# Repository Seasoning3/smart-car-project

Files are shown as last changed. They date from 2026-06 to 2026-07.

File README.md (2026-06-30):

# Smart Vehicle

## 1. Project Overview
This project implements a small embedded vehicle platform that integrates power distribution, PWM-based motor and steering control, camera-based ArUco marker detection, and a web-based control interface.

The main objective was to design and test a hardware-software integrated system.  
The project focused on power stability, actuator control, web-to-vehicle communication.

## 2. Project Images
### Vehicle Prototype
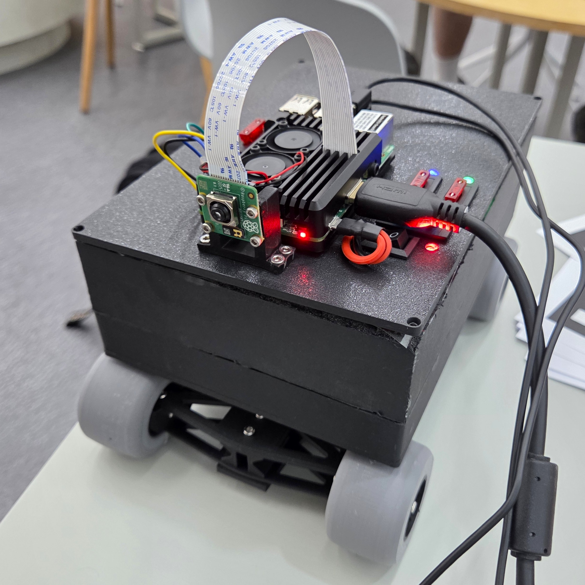
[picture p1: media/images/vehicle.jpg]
vehicle prototype


### Circuit Component Placement
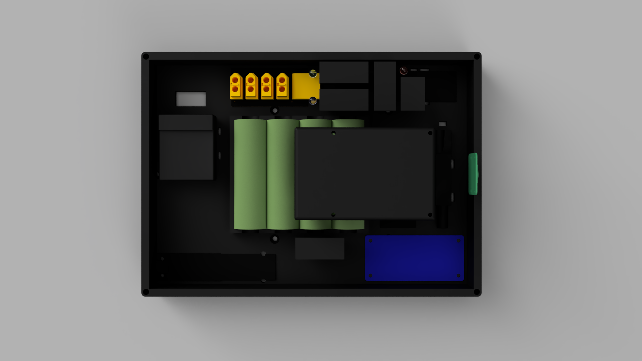
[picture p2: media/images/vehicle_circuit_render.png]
circuit_component_placement_render


### Circuit Diagram
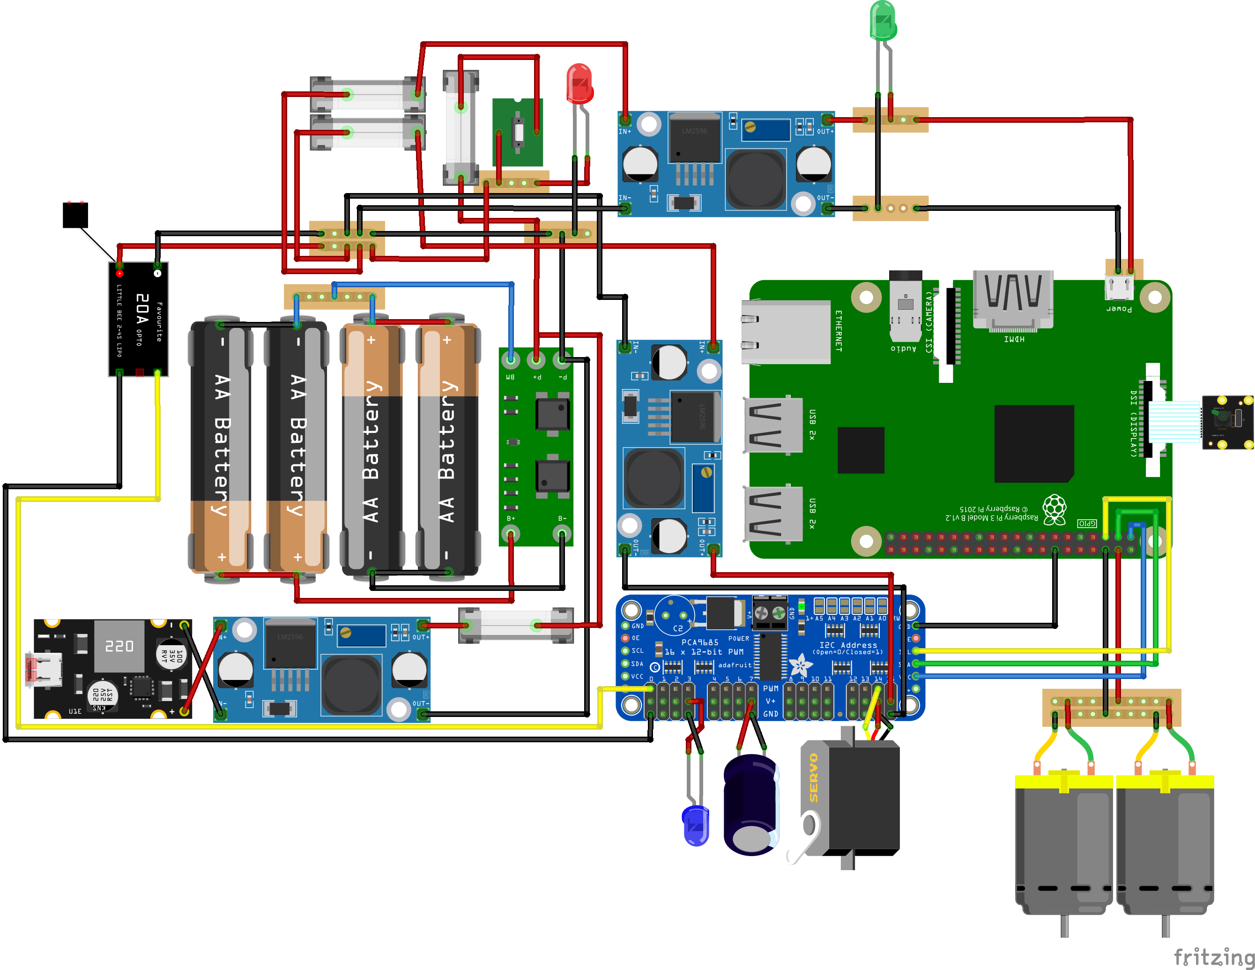
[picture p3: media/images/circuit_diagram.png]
circuit_diagram


### Web Interface
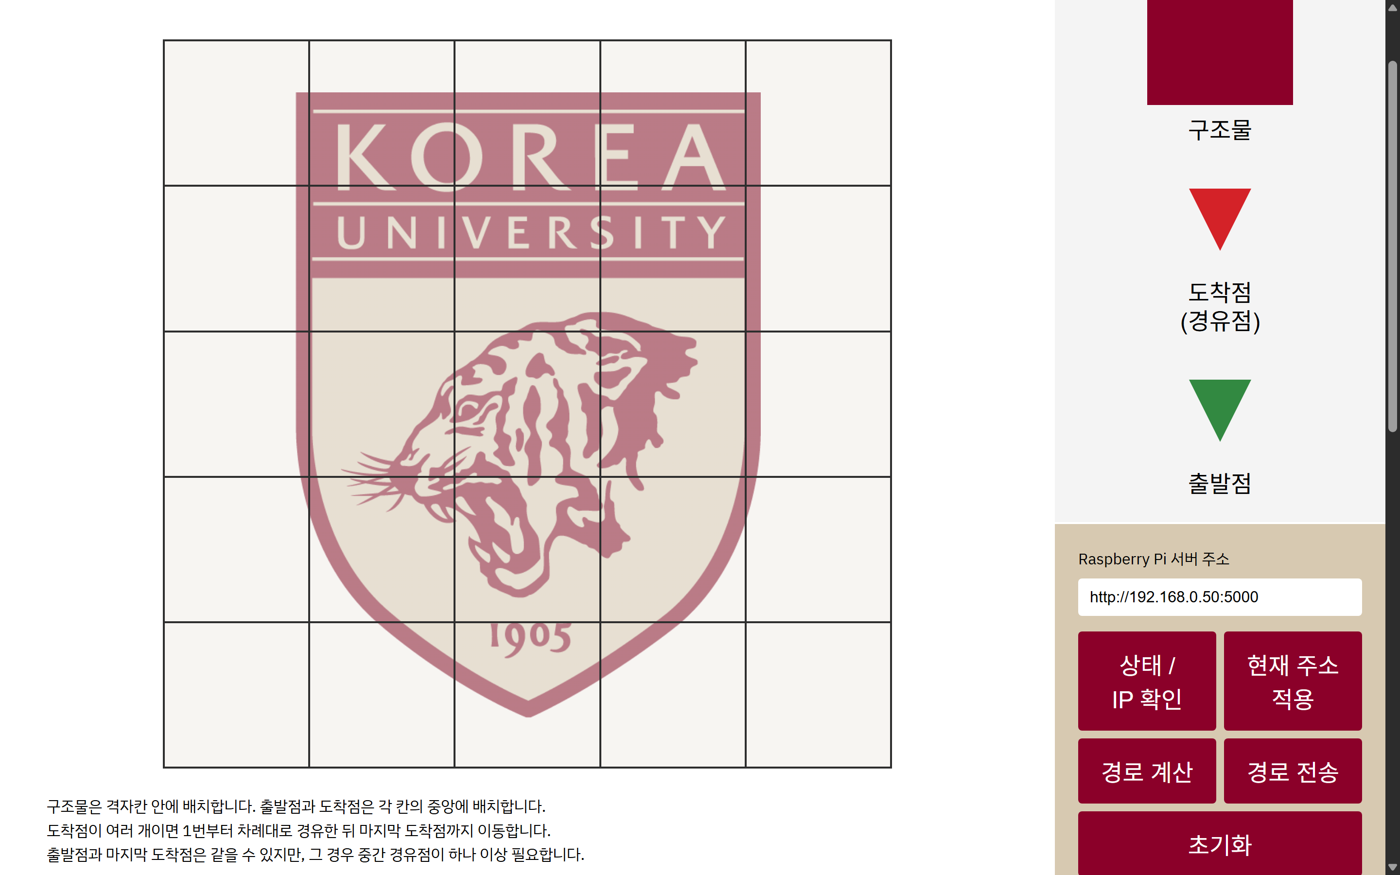
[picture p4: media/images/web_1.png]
web_upside

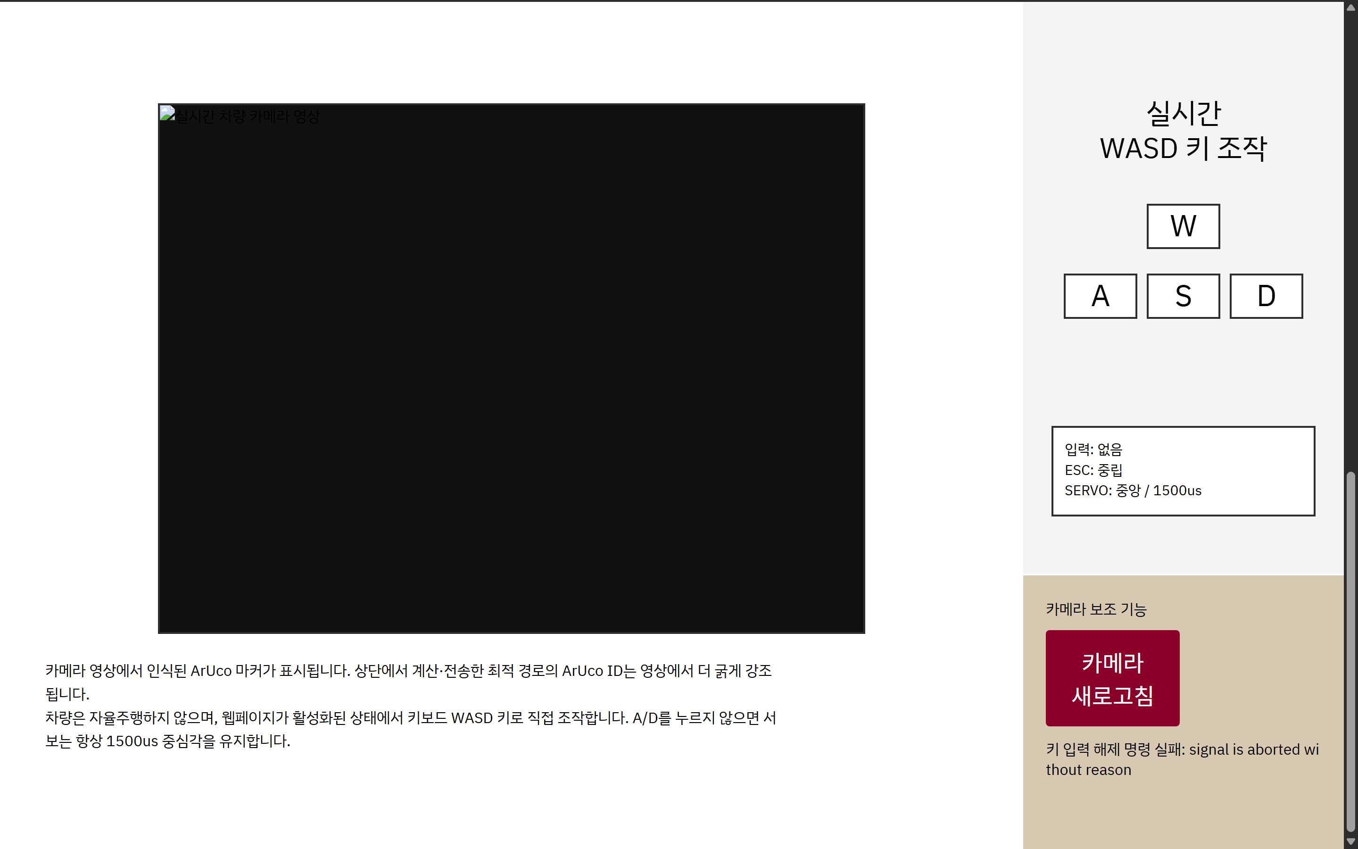
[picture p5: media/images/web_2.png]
web_downside


## 3. Key Features
- Raspberry Pi-based vehicle control server
- PWM control for ESC and steering servo through PCA9685
- Battery-powered hardware system with voltage conversion and fuse protection
- Web-based grid map interface for path setting
- WASD manual control interface
- Camera-based ArUco marker detection

## 4. System Flowchart
Web Interface  
|  
| HTTP / WebSocket  
v  
Raspberry Pi 3 Model B  
|  
| I2C  
v  
PCA9685 PWM Driver  
|  
| PWM Signal  
|  
|------------------> ESC --> DC Motor  
|  
|------------------> Steering Servo 

<br/>

Camera Module  
|  
v  
OpenCV / ArUco Marker Detection 

<br/>

Battery Pack  
|  
|----> Step-down Moduule / UBEC ---> Raspberry Pi, Servo, PWM Driver  
|  
|----> ESC ---> DC Motor

## 5. Hardware Components
### Computing and Sensing Unit
| Component | Specification | Role |
|---|---|---|
| Raspberry Pi 3 Model B | 5 V, 2.5 A | Main controller |
| Raspberry Pi Camera Module 3 | CSI-2 camera | ArUco marker recognition |
| Step-down Module | 5 V output | Stable power conversion |

### Actuation Unit
| Component | Specification | Role |
|---|---|---|
| PCA9685 | 16-channel PWM driver | Servo and ESC PWM signal generation |
| DC Motor | 7.2 V, 2.3 A | Rear-wheel drive |
| ESC | 2 - 3 S | DC motor speed control |
| Servo Motor | 7.4 V | Front steering control |
| UBEC | 2 - 8 S, 5 - 7.4 V output	| Stable power conversion |

### Power Supplying and Charging Unit
| Component | Specification | Role |
|---|---|---|
| Battery Pack | 2S2P battery configuration	| Main power source |
| BMS | 2S, 8.4 V, 20 A | Battery protection |
| Charging Module | 1 - 4 S, 5 - 26 V input | Battery charging |
| USB-C PD Trigger Module | 20 V PD output| Power supplying |

### Auxiliary Components
| Component | Specification | Role |
|---|---|---|
| Power Distribution Board | 200 A | Power distridution|
| Capacitor | 1000 µF | Voltage drop preventing |
| Blade Fuse | Rated according to current path | Overcurrent protection |
| LED(Red / Green, Blue)	| 2.2 V / 3.2 V, 20 mA | Status indicator |
| Hex Screw | M3, 8 mm / 10 mm / 12 mm | Unit assembling |
| Nut | M3 | Unit assembling |

## 6. Power Design
The power system was designed by separating the load requirements of each unit.

- The Raspberry Pi is powered by a regulated 5 V supply.
- The steering servo is powered through a UBEC to reduce voltage drop and supply stable current.
- The DC motor is powered through the ESC.
- LEDs are connected with a current-limiting resistor.
- Fuses are placed according to the estimated current of each power branch.

### Load-Side Power Budget
| Load | Voltage | Current | Estimated Power | Calculation |
|---|-----|---|---|---|
| Raspberry Pi 3 Model B | 5 V | 2.5 A | 12.50 W | 5 × 2.5 |
| Servo Motor| 7.4 V | 3.4 A | 25.16 W | 7.4 × 3.4 |
| DC Motor | 7.2 V | 2.3 A | 16.56 W | 7.2 × 2.3 |
| LED(Red / Green, Blue) | 2.2 V / 3.2 V | 20 mA | 0.044 W / 0.064 W | 2.2 × 0.02 / 3.2 × 0.02 |

### Main Load Subtotal
| Branch | Load-Side Power | Assumed Efficiency | Battery-Side Power | Calculation |
|---|---|-----|---|---|
| Raspberry Pi 3 Model B | 12.50 W | 85% | 14.71 W | 12.50 / 0.85 |
| Servo Motor| 25.16 W | 85% | 29.60 W | 25.16 / 0.85 |
| DC Motor | 16.56 W | Direct | 16.56 W | 16.56 |
| LEDs | 0.172 W | - | 0 W(Too small) | - |
| Total(Excluding LEDs) | 54.22 W | - | 60.87 W | 14.71 + 29.60 + 16.56 |

### Battery-Side Power Budget
| Battery Condition | Battery Voltage	| Estimated Battery-Side Power |	Estimated Current | Calculation |
|---|---|---|---|---|
| Fully charged |	8.4 V	| 60.87 W |	7.25 A | 60.87 / 8.4 = 7.25 |
| Nominal	| 7.4 V	| 60.87 W	| 8.23 A | 60.87 / 7.4 = 8.23 |
| Drain |	6.0 V	| 60.87 W	| 10.15 A | 60.87 / 6.0 = 10.15 |

### Fuse Selection
| Fuse Position	| Current Basis |	Recommended Fuse |
|---|---|---|
| Main battery line	| Normal current about 8–10 A |	15 A slow-blow fuse |
| Charging line	| 1–4 A charging current | 5 A fuse for 4 A charge / 2 A fuse for 1 A charge |
| Raspberry Pi 5 V branch	|	5 V, 2.5 A | 3 A fuse |
| Servo / PCA9685 power branch | 7.4 V, 3.4 A | 5 A fuse |

### BMS Selection
| Item | Basis | Recommended Specification |
|---|---|---|
| Battery type | 21700 Li-ion cells | 2S Li-ion BMS |
| Battery configuration | 2S2P pack | 8.4 V full-charge compatible |
| Normal current demand | about 8–10 A | 20 A continuous discharge minimum |
| Peak current demand | DC motor startup + servo load | 30 A continuous discharge preferred |
| Peak discharge rating | short motor/servo surge | 40–60 A peak discharge preferred |
| Charging current | 2–3 A charging branch | 3–5 A charge rating |
| Cell balancing | 2 cells in series | Balancing function recommended |

The power design was checked using Ohm's law, Kirchhoff's laws, and basic circuit theory:

- V = I × R (Ohm's law)
- P = V × I (Power equation)
- R = (V_supply - V_f) / I (Current-limiting resistor)
- I_1 + I_2 + I_3 + ⋯ + I_n = 0 (Kirchhoff's current law, KCL)
- V_1 + V_2 + V_3 + ⋯ + V_n = 0 (Kirchhoff's voltage law, KVL)
- I_total = I_1 + I_2 + I_3 + ⋯ + I_n (Current addition in a parallel circuit)
- V_supply = V_1 + V_2 + V_3 + ⋯ + V_n (Voltage addition in a series circuit)
- C_pack = C_1 + C_2 + ⋯ + C_n (Capacity addition in parallel)
- I_cell ≈ I_pack / n (Current division in parallel)
- η = P_out / P_in (Power conversion efficiency)

## 7. Motor and Steering Control
The ESC and steering servo are controlled using PWM signals generated by the PCA9685.

- ESC channel: 0
- PWM frequency: 50 Hz
- Neutral pulse width: 1500 µs
- Steering control: left/right angle adjustment through PWM
- Stop logic: ESC signal returns to neutral pulse width

The steering servo is designed to return to the neutral position when no active steering command is given.

## 8. Main Software Functions
- Web server for vehicle command transmission
- Manual driving control using WASD keys
- PWM signal generation for ESC and servo
- Camera streaming
- ArUco marker detection
- Emergency stop and neutral control logic
- Path and marker data loading from a grid mapping file

## 9. Limitations
- Camera recognition is sensitive to lighting conditions.
- Battery voltage drop can affect actuator stability.
- Mechanical steering precision is limited by servo calibration.
- The current system is designed for a small test environment.
- The project uses a Simple Pathfinding Algorithm(BFS).

## 10. Future Improvements
- Improve lighting control and camera exposure settings.
- Add battery voltage monitoring
- Calibrate the servo center and steering pulse range more precisely.
- Test the system on a larger and more complex track.
- Apply A* or other advanced path-planning algorithms.

## 11. Team Member Roles
**Kim Minseong [[Seasoning3](https://github.com/Seasoning3)]**
- Circuit Design
- Circuit configuration
- Vehicle Design
- Vehicle Making
- Web Programming
- Vehicle Programming
- Test Environment Setup
- Archiving

**Park Gibeom [[gibeom308](https://github.com/gibeom308)]**
- Test Environment Setup

**Paek Youngjae [[Paek Yeongjae](https://github.com/paekyeongjae)]**
- Test Environment Setup

**Jeon Seungmin [[tmdals914](https://github.com/tmdals914)]**
- Vehicle Programming
- Test Environment Setup

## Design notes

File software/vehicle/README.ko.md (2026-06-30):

# README.ko.md

이 README는 `raspberry_pi_car_server.py` 서버를 라즈베리파이에서 처음부터 실행하기 위한 전체 셋업 절차입니다.  
현재 서버는 자율주행을 수행하지 않고, 웹 기반 지도 표시·경로 마커 하이라이트·실시간 카메라·WASD 수동 조작만 담당합니다.

## 1. 최종 파일 구조

라즈베리파이에 아래 구조로 파일을 배치합니다.

```text
smart_vehicle/
├─ raspberry_pi_car_server.py
├─ grid_marker_map.json
├─ web.html
└─ README.md
```

각 파일 역할은 다음과 같습니다.

| File | Role |
|---|---|
| `raspberry_pi_car_server.py` | Flask 서버, PCA9685 PWM 제어, 카메라 스트리밍, ArUco 인식 |
| `grid_marker_map.json` | 5×5 격자 좌표와 실제 ArUco marker ID 매핑 |
| `web.html` | 웹 UI |
| `README.md` | 서버 설치 및 실행 설명 |

## 2. 하드웨어 연결 기준

현재 서버 코드는 다음 연결을 기준으로 합니다.

| Device | Connection |
|---|---|
| ESC signal | PCA9685 channel 0 |
| servo signal | PCA9685 channel 14 |
| PCA9685 SDA | Raspberry Pi SDA |
| PCA9685 SCL | Raspberry Pi SCL |
| PCA9685 GND | Raspberry Pi GND |
| Servo/ESC signal GND | Raspberry Pi/PCA9685 GND와 공통 접지 |
| Camera | CSI camera |

서버 코드 상단 기본값은 다음과 같습니다.

```python
ESC_CHANNEL = 0
SERVO_CHANNEL = 14
PWM_FREQ = 50
```

## 3. Raspberry Pi OS 기본 준비

라즈베리파이를 켠 뒤 터미널에서 먼저 업데이트합니다.

```bash
sudo apt update
sudo apt upgrade -y
```

필수 도구를 설치합니다.

```bash
sudo apt install -y python3-pip python3-venv git i2c-tools v4l-utils
```

## 4. I2C 활성화

PCA9685를 사용하려면 I2C가 켜져 있어야 합니다.

```bash
sudo raspi-config
```

아래 순서로 들어갑니다.

```text
Interface Options
→ I2C
→ Enable
```

재부팅합니다.

```bash
sudo reboot
```

재부팅 후 PCA9685가 잡히는지 확인합니다.

```bash
i2cdetect -y 1
```

정상이라면 보통 `0x40` 주소가 보입니다.

```text
     0 1 2 3 4 5 6 7 8 9 a b c d e f
40: 40 -- -- -- -- -- -- -- -- -- -- -- -- -- -- --
```

`40`이 보이지 않으면 다음을 확인합니다.

- PCA9685 VCC 연결
- PCA9685 GND 연결
- SDA/SCL 배선
- I2C 활성화 여부
- 라즈베리파이와 PCA9685의 공통 GND

## 5. 카메라 활성화 및 확인

라즈베리파이 카메라 모듈을 사용하는 경우 카메라가 인식되는지 확인합니다.

```bash
rpicam-hello --list-cameras
```

위 명령이 없으면 다음을 시도합니다.

```bash
libcamera-hello --list-cameras
```

카메라 사진 테스트:

```bash
rpicam-still -o test.jpg
```

또는:

```bash
libcamera-still -o test.jpg
```

CSI 카메라가 여기서는 잡히는데 웹에서 검은 화면이 나오면 서버 실행 시 Picamera2 backend를 강제합니다.

```bash
CAMERA_BACKEND=picamera2 python3 raspberry_pi_car_server.py
```

## 6. 프로젝트 폴더 만들기

홈 디렉터리에 서버 폴더를 만듭니다.

```bash
cd ~
mkdir -p smart_vehicle
cd smart_vehicle
```

아래 파일을 같은 구조로 복사합니다.

```text
smart_vehicle/
├─ raspberry_pi_car_server.py
├─ grid_marker_map.json
└─ web.html
```

## 7. Python 가상환경 만들기

라즈베리파이에서 프로젝트 폴더로 이동합니다.

```bash
cd ~/smart_vehicle
```

가상환경을 만듭니다.

```bash
python3 -m venv --system-site-packages smartcar
```

가상환경에 들어갑니다.

```bash
source smartcar/bin/activate
```

프롬프트 앞에 `(smartcar)`가 보이면 가상환경에 들어간 상태입니다.

```text
(smartcar) pi@raspberrypi:~/smart_vehicle $
```

가상환경에서 나가려면 다음을 입력합니다.

```bash
deactivate
```

## 8. Python 패키지 설치

가상환경 안에서 pip를 업데이트합니다.

```bash
python -m pip install --upgrade pip setuptools wheel
```

서버 기본 패키지를 설치합니다.

```bash
pip install flask numpy adafruit-circuitpython-pca9685
```

OpenCV는 ArUco 기능 때문에 `opencv-contrib-python`이 필요합니다.

```bash
pip install opencv-contrib-python
```

라즈베리파이 3에서 위 설치가 너무 오래 걸리거나 실패하면, 먼저 현재 OpenCV에 ArUco가 포함되어 있는지 확인합니다.

```bash
python3 - <<'PY'
import cv2
print("OpenCV:", cv2.__version__)
print("Has aruco:", hasattr(cv2, "aruco"))
PY
```

`Has aruco: True`가 나오면 추가 설치 없이 사용할 수 있습니다.

CSI 카메라를 Picamera2로 쓸 경우 보통 apt 패키지가 필요합니다.

```bash
sudo apt install -y python3-picamera2
```

가상환경을 `--system-site-packages`로 만들었기 때문에 apt로 설치된 `picamera2`를 가상환경 안에서도 사용할 수 있습니다.

## 9. 서버 설정값 확인

`raspberry_pi_car_server.py` 상단에서 다음 값을 실제 차량에 맞게 확인합니다.

```python
ESC_CHANNEL = 0
SERVO_CHANNEL = 14
PWM_FREQ = 50

ESC_NEUTRAL_US = 1500
ESC_FORWARD_US = 1641
ESC_REVERSE_US = 1453

SERVO_CENTER_ANGLE = 20
SERVO_LEFT_ANGLE = 32
SERVO_RIGHT_ANGLE = 8
SERVO_CENTER_US = 1500
```

중요한 기준은 다음입니다.

| Setting | Meaning |
|---|---|
| `ESC_NEUTRAL_US = 1500` | ESC 중립 |
| `ESC_FORWARD_US` | W 입력 시 전진 PWM |
| `ESC_REVERSE_US` | S 입력 시 후진 PWM |
| `SERVO_CENTER_US = 1500` | 조향 중립 PWM, 유지 |
| `SERVO_LEFT_ANGLE` | A 입력 시 좌측 조향 각도 |
| `SERVO_RIGHT_ANGLE` | D 입력 시 우측 조향 각도 |

현재 조향 로직은 다음과 같습니다.

```text
A 입력 → SERVO_LEFT_ANGLE
D 입력 → SERVO_RIGHT_ANGLE
A/D 입력 없음 → SERVO_CENTER_US = 1500
A와 D 동시 입력 → SERVO_CENTER_US = 1500
```

즉, `A` 또는 `D`로 조작하지 않으면 서보는 항상 중립 각도입니다.

## 10. grid_marker_map.json 설정

마커 매핑은 HTML 내부가 아니라 `grid_marker_map.json`에서 관리합니다.

기본 형식:

```json
{
  "description": "5x5 grid-cell to ArUco marker ID mapping. Edit this file only when physical marker placement changes.",
  "coordinate_rule": "grid[row][col], where row=0 is top and col=0 is left",
  "rows": 5,
  "cols": 5,
  "grid": [
    [0, 1, 2, 3, 4],
    [5, 6, 7, 8, 9],
    [10, 11, 12, 13, 14],
    [15, 16, 17, 18, 19],
    [20, 21, 22, 23, 24]
  ]
}
```

좌표 규칙:

```text
grid[row][col]
row = 위에서 아래, 0부터 시작
col = 왼쪽에서 오른쪽, 0부터 시작
```

예를 들어 왼쪽 위 칸 중앙의 실제 ArUco ID가 17이면 첫 번째 값을 17로 바꿉니다.

```json
"grid": [
  [17, 1, 2, 3, 4],
  [5, 6, 7, 8, 9],
  [10, 11, 12, 13, 14],
  [15, 16, 17, 18, 19],
  [20, 21, 22, 23, 24]
]
```

단, 실제 운용에서는 같은 ArUco ID를 여러 칸에 중복 배치하지 않는 것이 좋습니다.

## 11. 서버 실행

프로젝트 폴더로 이동합니다.

```bash
cd ~/smart_vehicle
```

가상환경에 들어갑니다.

```bash
source smartcar/bin/activate
```

기본 실행:

```bash
python3 raspberry_pi_car_server.py
```

CSI 카메라를 강제할 때:

```bash
CAMERA_BACKEND=picamera2 python3 raspberry_pi_car_server.py
```

서버가 정상 실행되면 보통 다음과 비슷하게 표시됩니다.

```text
* Running on http://0.0.0.0:5000
```

## 12. 웹 접속

PC와 라즈베리파이가 같은 Wi-Fi 또는 같은 핫스팟에 연결되어 있어야 합니다.

라즈베리파이 IP 확인:

```bash
hostname -I
```

예를 들어 IP가 `192.168.0.50`이면 PC 브라우저에서 다음 주소로 접속합니다.

```text
http://192.168.0.50:5000
```

웹페이지가 라즈베리파이에서 직접 열렸다면 `현재 주소 적용` 버튼으로 서버 주소를 자동 적용할 수 있습니다.

## 13. 웹 조작 방법

### 13.1 지도 조작

| Tool | Role |
|---|---|
| 구조물 | 차량이 지나갈 수 없는 칸 |
| 출발점 | 경로 시작 위치 |
| 도착점 / 경유점 | 방문해야 할 지점 |

절차:

1. 구조물을 배치합니다.
2. 출발점을 배치합니다.
3. 도착점 또는 경유점을 배치합니다.
4. `경로 계산`을 누릅니다.
5. `경로 전송`을 누릅니다.
6. 카메라 화면에서 최적 경로에 해당하는 ArUco ID가 하이라이트되는지 확인합니다.

경로 전송은 카메라 화면에서 최적 경로 마커를 강조하기 위한 용도입니다.

### 13.2 차량 수동 조작

| Key | Action |
|---|---|
| W | 전진 |
| S | 후진 |
| A | 좌측 조향 |
| D | 우측 조향 |

키를 떼면 해당 방향 상태가 `false`로 서버에 전송됩니다.  
W/S가 모두 `false`이면 ESC는 1500us입니다.  
A/D가 모두 `false`이면 서보는 1500us입니다.

## 14. 서버 API

| API | Method | Role |
|-----|-----|---|
| `/` | GET | 웹 UI |
| `/video_feed` | GET | MJPEG 카메라 스트림 |
| `/api/drive_state` | POST | WASD 상태 수신 후 ESC/서보 PWM 갱신 |
| `/api/route_markers` | POST | 최적 경로 marker ID 등록 |
| `/api/grid_marker_map` | GET | `grid_marker_map.json` 로드 |
| `/api/status` | GET | 서버, PWM, 카메라, 마커 상태 확인 |
| `/api/camera_status` | GET | 카메라 backend, index, black frame 상태 확인 |
| `/api/neutral` | POST | 내부 안전용 중립 PWM |
| `/emergency_stop` | GET/POST | 내부 안전용 중립 PWM |

웹 UI에는 중립 전송 버튼을 두지 않습니다. `/api/neutral`과 `/emergency_stop`은 안전용으로 서버에만 남아 있습니다.

## 15. 상태 확인

전체 상태:

```text
http://라즈베리파이IP:5000/api/status
```

카메라 상태:

```text
http://라즈베리파이IP:5000/api/camera_status
```

마커 매핑 상태:

```text
http://라즈베리파이IP:5000/api/grid_marker_map
```

카메라 상태에서 확인할 주요 항목:

| Field | Meaning |
|---|---|
| `backend` | 사용 중인 카메라 방식 |
| `selected_index` | OpenCV 카메라 번호 |
| `opened` | 카메라 열림 여부 |
| `black_frame_count` | 검은 프레임 감지 횟수 |
| `last_error` | 마지막 카메라 오류 |

## 16. 자주 발생하는 문제

### 16.1 웹페이지는 열리는데 차량이 움직이지 않음

확인 순서:

```bash
i2cdetect -y 1
```

`40`이 보이지 않으면 PCA9685 연결 또는 I2C 설정 문제입니다.

서버 상태 확인:

```text
http://라즈베리파이IP:5000/api/status
```

`hardware_available`이 `false`이면 Python에서 PCA9685 관련 라이브러리 또는 I2C 접근에 실패한 것입니다.

패키지 재설치:

```bash
pip install adafruit-circuitpython-pca9685
```

### 16.2 W/S를 눌러도 모터가 돌지 않음

확인할 것:

- ESC signal이 PCA9685 channel 0에 꽂혀 있는지
- ESC와 PCA9685/Raspberry Pi GND가 공통인지
- ESC가 arming 되었는지
- 배터리 전압이 충분한지
- `ESC_FORWARD_US` 값이 너무 낮지 않은지

전진 PWM을 조금 올려 테스트할 수 있습니다.

```python
ESC_FORWARD_US = 1650
```

너무 크게 올리면 갑자기 튈 수 있으므로 작은 폭으로만 조정합니다.

### 16.3 A/D를 누르지 않았는데 서보가 한쪽으로 돌아감

현재 코드상 A/D 입력이 없으면 서버는 반드시 `SERVO_CENTER_US = 1500`을 출력합니다. 그래도 한쪽으로 돌아가면 원인은 코드보다 하드웨어 보정 문제일 가능성이 큽니다.

확인할 것:

- 서보혼이 기계적으로 중앙에 맞게 꽂혔는지
- 실제 서보 중앙이 1500us인지
- PCA9685 GND와 서보 전원 GND가 공통인지
- 서보 전원이 충분한지

기계적 중앙이 다르면 서보혼을 다시 장착하는 것이 먼저입니다.

### 16.4 카메라 화면에 `Camera frame unavailable` 또는 검은 화면이 나옴

상태 확인:

```text
http://라즈베리파이IP:5000/api/camera_status
```

CSI 카메라라면:

```bash
CAMERA_BACKEND=picamera2 python3 raspberry_pi_car_server.py
```

OS 장치 확인:

```bash
ls -l /dev/video*
v4l2-ctl --list-devices
```

CSI 카메라 확인:

```bash
rpicam-hello --list-cameras
libcamera-hello --list-cameras
```

### 16.5 ArUco가 인식되지 않음

확인할 것:

- 서버의 `ARUCO_DICT_NAME`이 실제 생성한 ArUco dictionary와 같은지
- 마커가 너무 작지 않은지
- 조명이 너무 어둡거나 반사가 심하지 않은지
- 카메라 초점이 맞는지
- 마커가 화면에서 충분히 크게 보이는지
- `opencv-contrib-python` 또는 `cv2.aruco`가 설치되어 있는지

확인 명령:

```bash
python3 - <<'PY'
import cv2
print(cv2.__version__)
print(hasattr(cv2, "aruco"))
PY
```

`False`가 나오면 ArUco 모듈이 없는 OpenCV입니다.

### 16.6 경로 하이라이트가 실제 마커와 다름

`grid_marker_map.json`이 실제 보드의 마커 배치와 맞지 않는 상태입니다.

확인할 것:

- 왼쪽 위 칸이 `grid[0][0]`인지
- 오른쪽 아래 칸이 `grid[4][4]`인지
- 실제 부착한 ArUco ID와 JSON 값이 일치하는지
- 같은 ID를 여러 칸에 중복으로 넣지 않았는지

## 17. 서버를 종료하는 방법

터미널에서 서버가 실행 중이면 `Ctrl + C`를 누릅니다.

가상환경에서 나가려면:

```bash
deactivate
```

## 18. 자동 실행이 필요한 경우

부팅 후 서버를 자동 실행하려면 systemd 서비스를 만들 수 있습니다.

서비스 파일 생성:

```bash
sudo nano /etc/systemd/system/carserver.service
```

아래 내용을 붙여 넣습니다. 사용자 이름과 경로가 다르면 수정합니다.

```ini
[Unit]
Description=Manual ArUco Car Server
After=network-online.target
Wants=network-online.target

[Service]
User=pi
WorkingDirectory=/home/pi/smart_vehicle
Environment=CAMERA_BACKEND=auto
ExecStart=/home/pi/smart_vehicle/smartcar/bin/python /home/pi/smart_vehicle/raspberry_pi_car_server.py
Restart=on-failure
RestartSec=3

[Install]
WantedBy=multi-user.target
```

서비스 적용:

```bash
sudo systemctl daemon-reload
sudo systemctl enable carserver.service
sudo systemctl start carserver.service
```

상태 확인:

```bash
sudo systemctl status carserver.service
```

로그 확인:

```bash
journalctl -u carserver.service -f
```

중지:

```bash
sudo systemctl stop carserver.service
```

자동 실행 해제:

```bash
sudo systemctl disable carserver.service
```

## 19. 최종 실행 체크리스트

아래 순서대로 확인합니다.

```text
1. I2C enabled
2. i2cdetect -y 1에서 0x40 확인
3. 카메라가 rpicam/libcamera 또는 /dev/video*에서 확인됨
4. Python 가상환경 생성 완료
5. Flask, OpenCV, PCA9685 라이브러리 설치 완료
6. grid_marker_map.json이 실제 보드 마커 ID와 일치
7. 서버 실행
8. PC에서 http://라즈베리파이IP:5000 접속
9. /api/status 확인
10. /api/camera_status 확인
11. W/A/S/D 조작 테스트
12. 경로 계산 후 카메라 화면에서 route marker highlight 확인
```

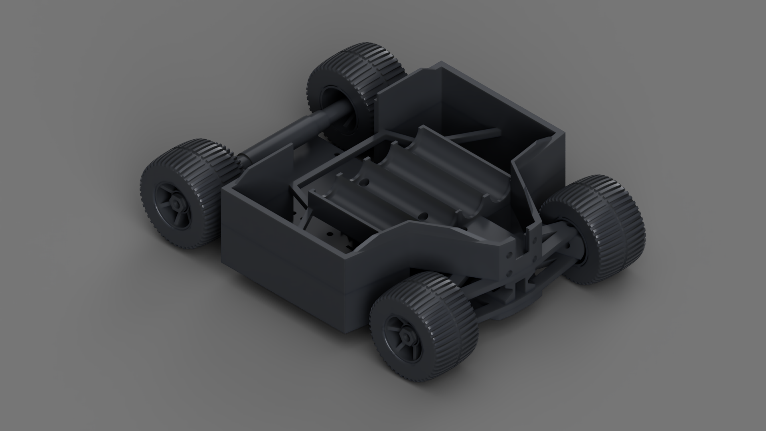
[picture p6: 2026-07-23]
hardware/cad/renders/07-cover-holder-removed-without-electronics.png

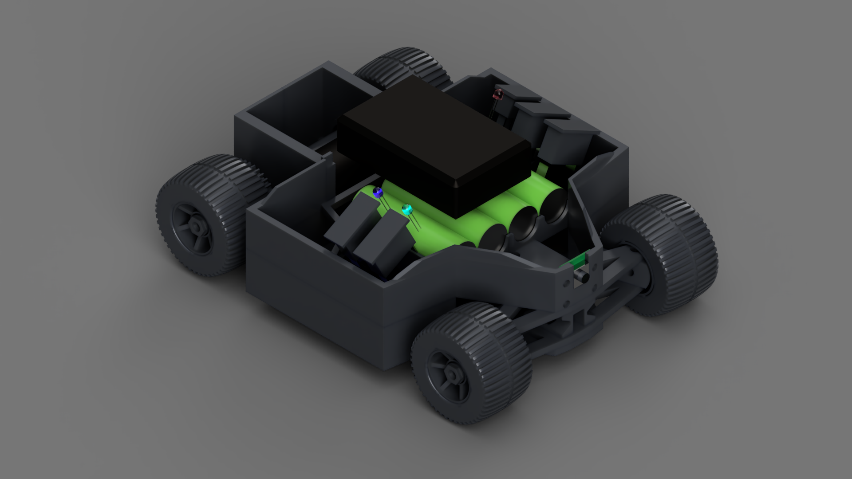
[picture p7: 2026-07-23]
hardware/cad/renders/03-cover-holder-removed.png

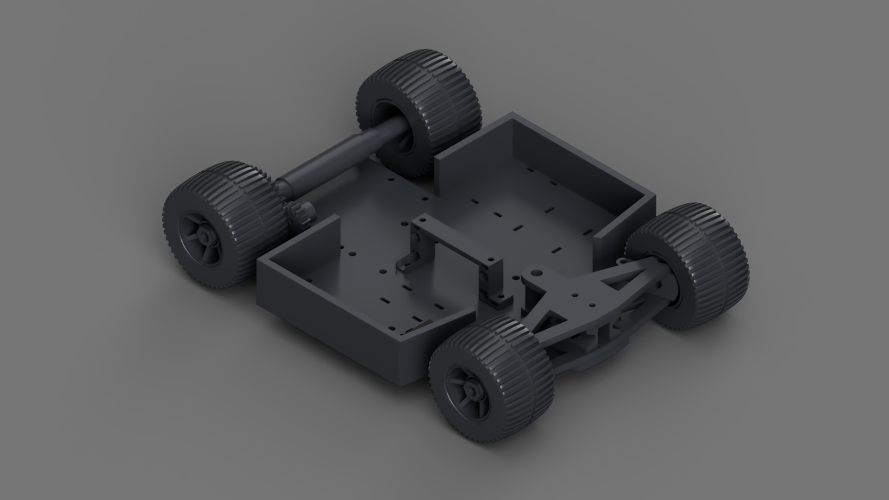
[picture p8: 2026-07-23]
hardware/cad/renders/08-cover-holder-frame-removed-without-electronics.png

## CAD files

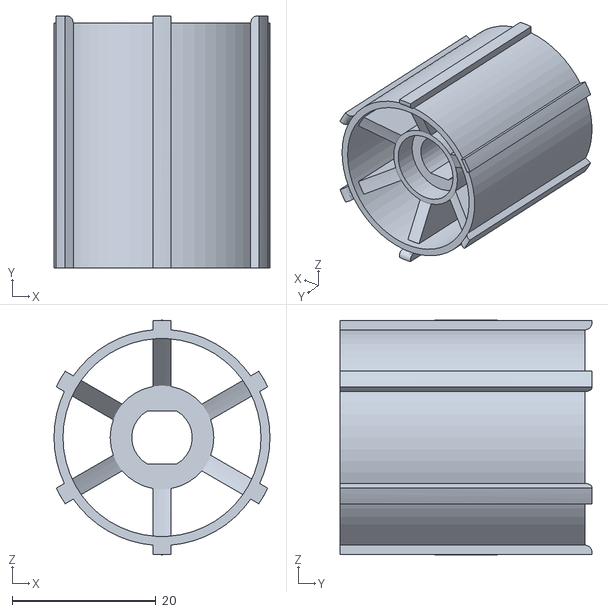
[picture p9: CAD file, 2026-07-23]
hardware/cad/stl/Rear_Rim.stl
30.0 x 35.0 x 32.6

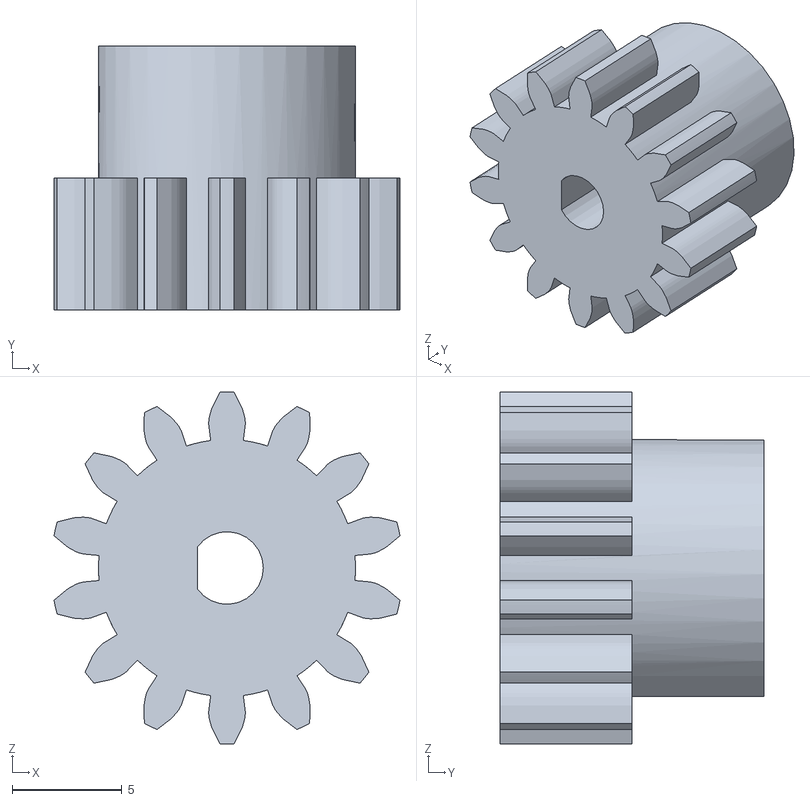
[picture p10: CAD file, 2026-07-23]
hardware/cad/stl/Pinion_Gear.stl
15.7 x 12.0 x 16.0

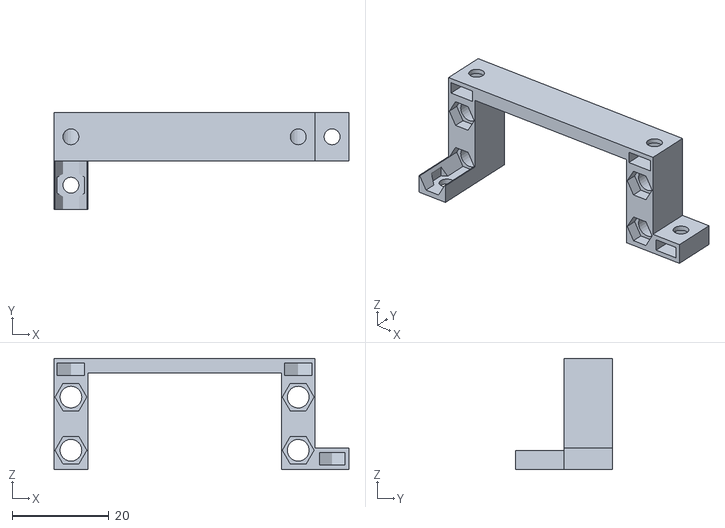
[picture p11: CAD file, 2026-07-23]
hardware/cad/stl/Servo_Holder.stl
61.0 x 20.0 x 23.0

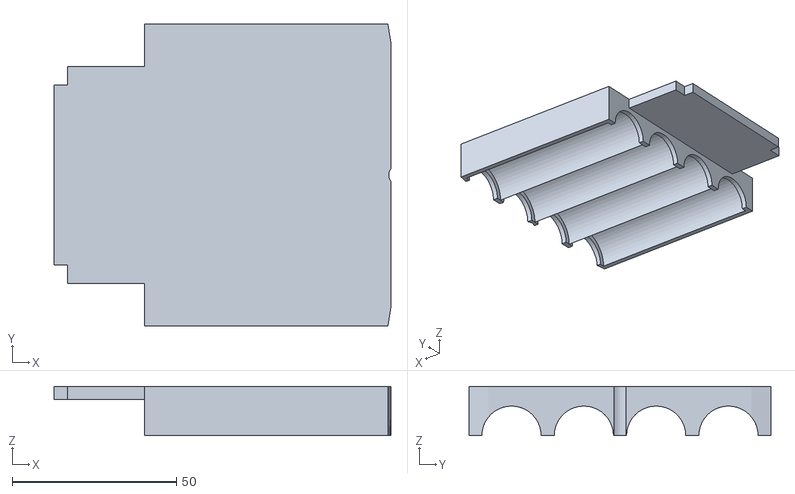
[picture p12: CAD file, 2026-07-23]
hardware/cad/stl/Battery_Holder.stl
102.5 x 92.0 x 15.0

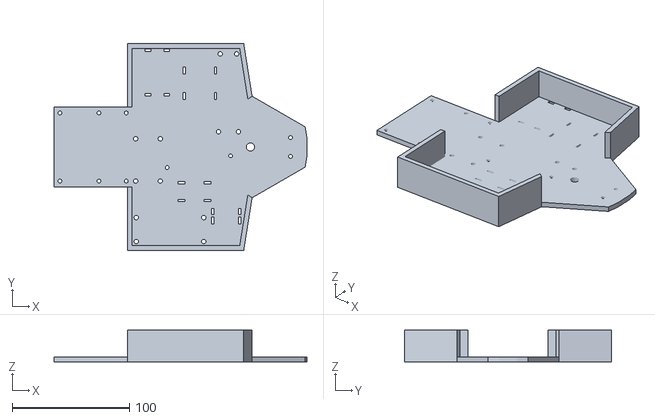
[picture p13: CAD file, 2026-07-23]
hardware/cad/stl/Chassie.stl
215.4 x 176.0 x 27.0

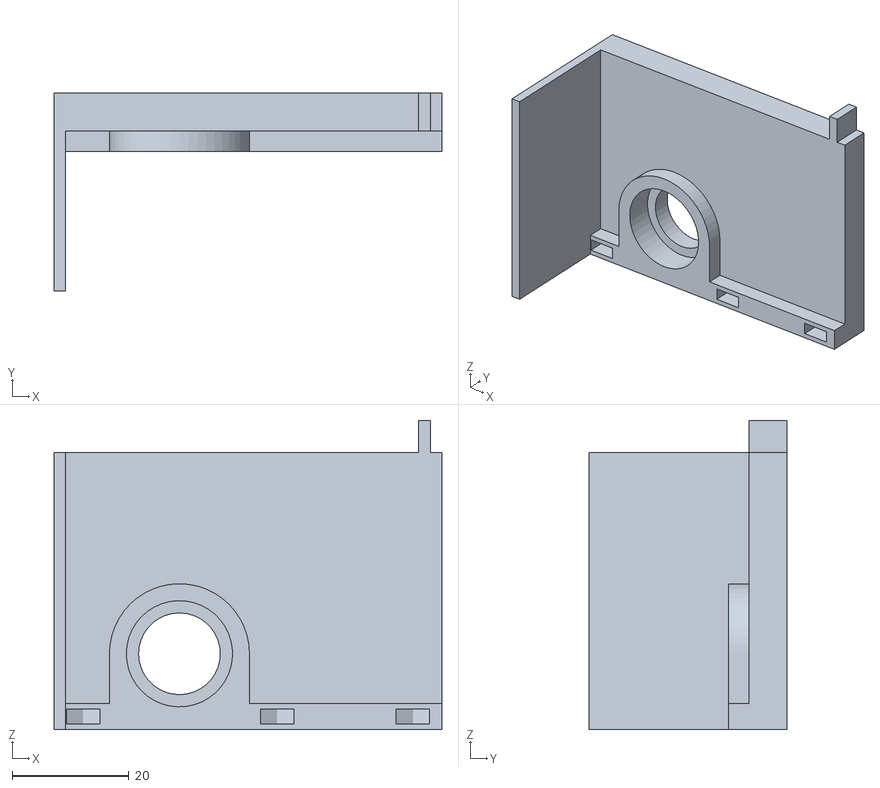
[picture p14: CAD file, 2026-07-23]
hardware/cad/stl/Wheel_Axle_Holder_Left.stl
66.5 x 33.9 x 53.0

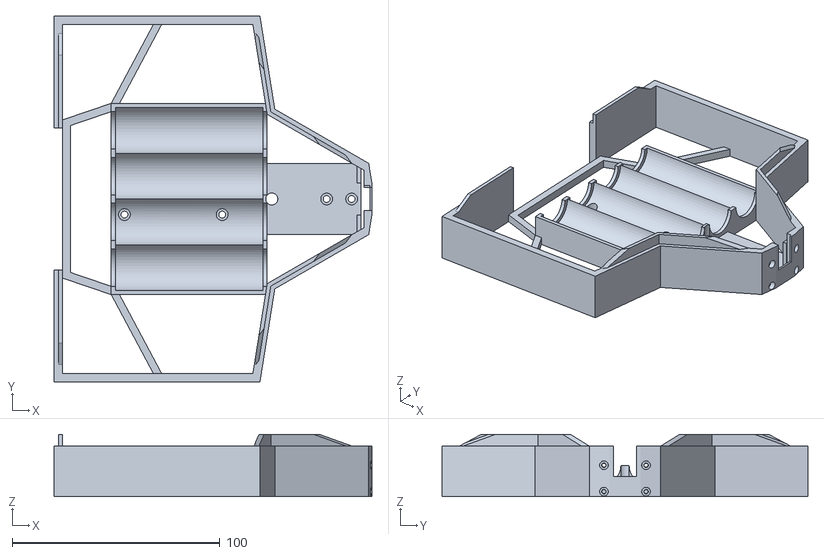
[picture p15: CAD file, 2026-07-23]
hardware/cad/stl/Frame.stl
152.9 x 176.0 x 29.9

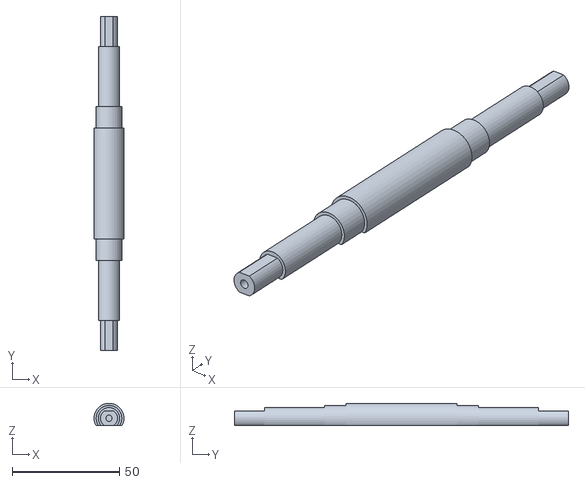
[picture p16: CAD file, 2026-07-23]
hardware/cad/stl/Rear_Wheel_Axle.stl
14.0 x 156.0 x 10.5

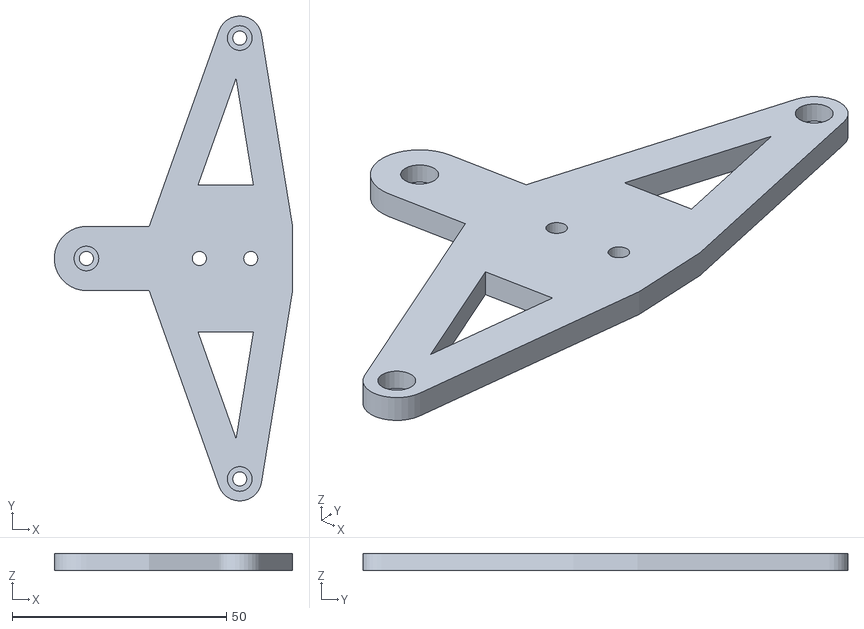
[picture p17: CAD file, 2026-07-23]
hardware/cad/stl/Front_Upper_BOM.stl
55.6 x 113.3 x 4.00

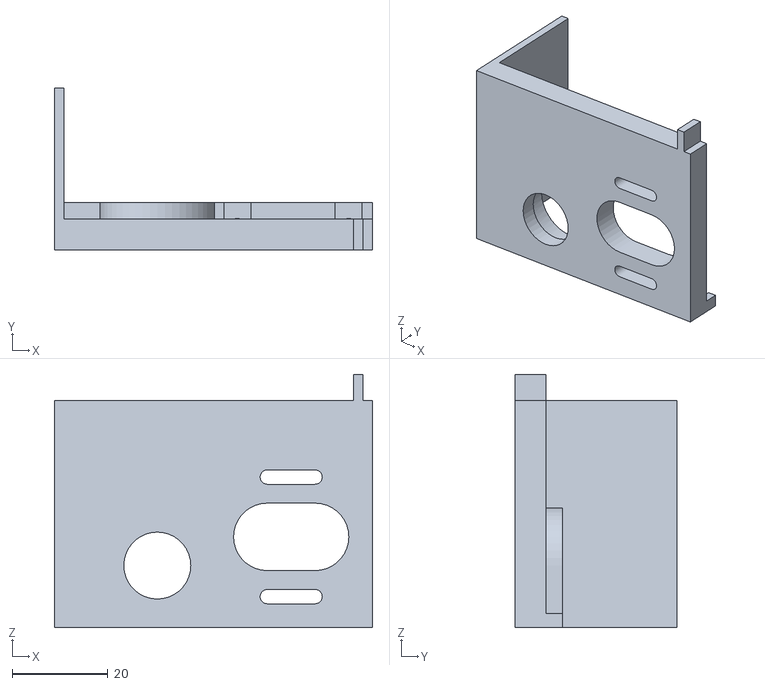
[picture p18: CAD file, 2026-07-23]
hardware/cad/stl/Wheel_Axle_Holder_Right.stl
66.5 x 34.0 x 53.0

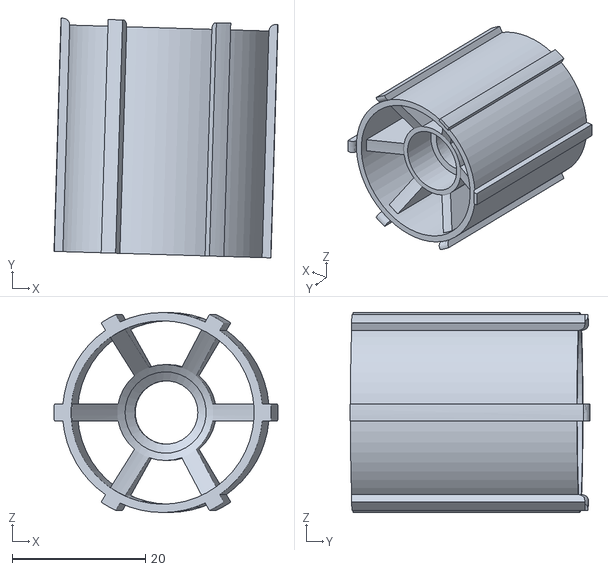
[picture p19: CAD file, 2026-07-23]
hardware/cad/stl/Front_Rim.stl
33.6 x 36.0 x 30.0

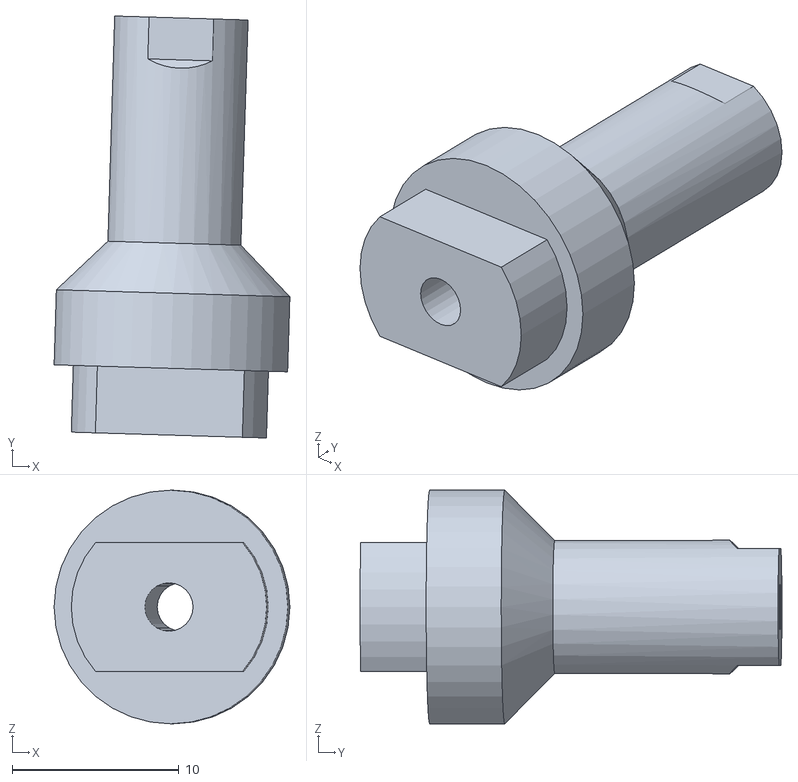
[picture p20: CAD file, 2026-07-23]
hardware/cad/stl/Front_Wheel_Axle.stl
14.1 x 25.3 x 14.0

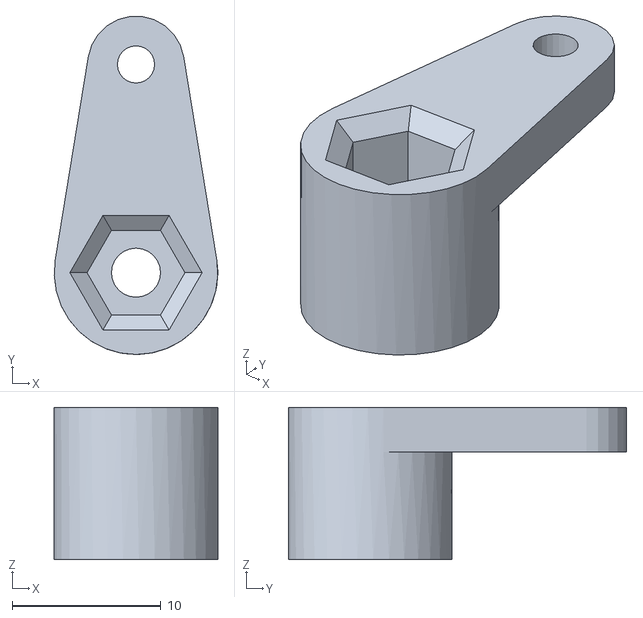
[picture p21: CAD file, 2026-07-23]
hardware/cad/stl/Servo_Saver_Lower.stl
11.0 x 22.7 x 10.2

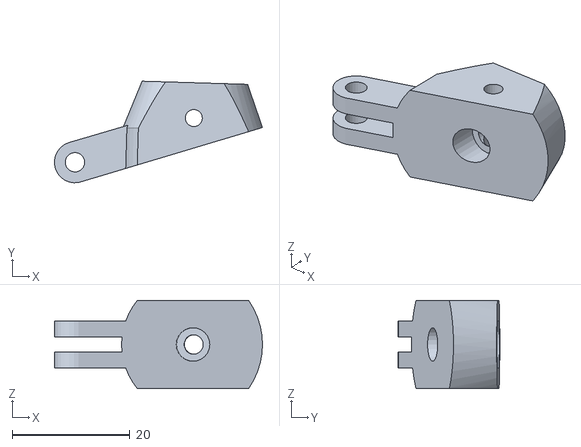
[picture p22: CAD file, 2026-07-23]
hardware/cad/stl/Front_Wheel_Hub.stl
35.4 x 17.3 x 15.0

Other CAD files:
hardware/cad/stl/Front_Lower_BOM.stl
hardware/cad/stl/Steering_Push_Pin.stl
hardware/cad/stl/Front_BOM_Block.stl
hardware/cad/stl/Tread_Tire.stl
hardware/cad/stl/Cover.stl
hardware/cad/stl/Servo_Saver_Upper.stl
hardware/cad/stl/Spur_Gear.stl
hardware/cad/stl/Wheel_Lock_Nut.stl

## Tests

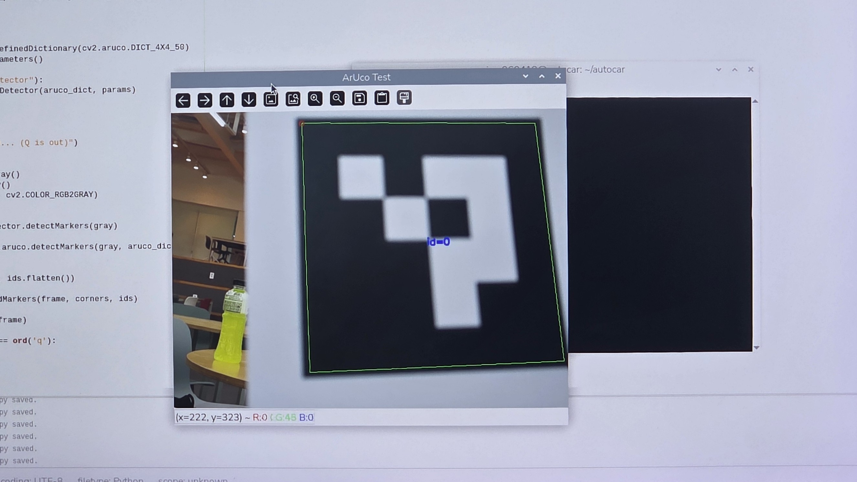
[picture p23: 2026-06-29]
media/images/ArUco_test.jpg

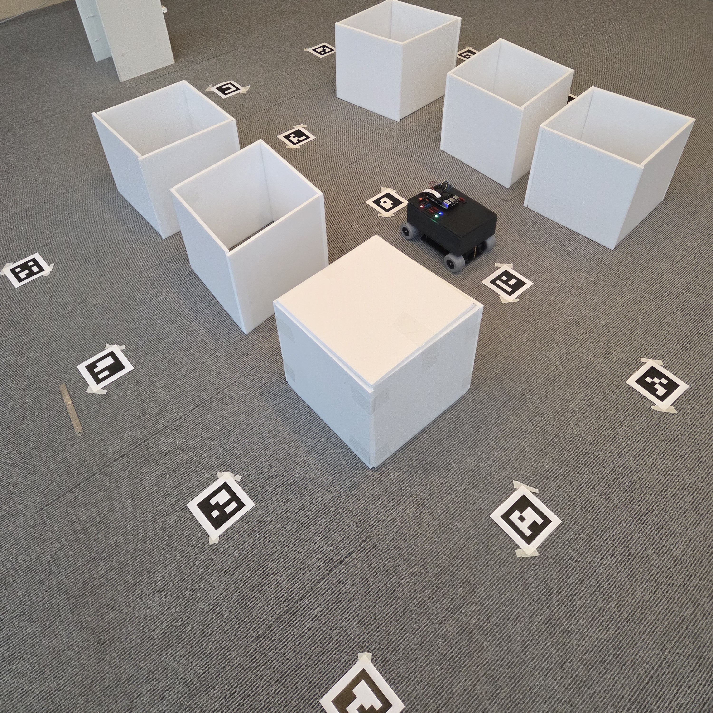
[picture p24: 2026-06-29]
media/images/test_2.jpg

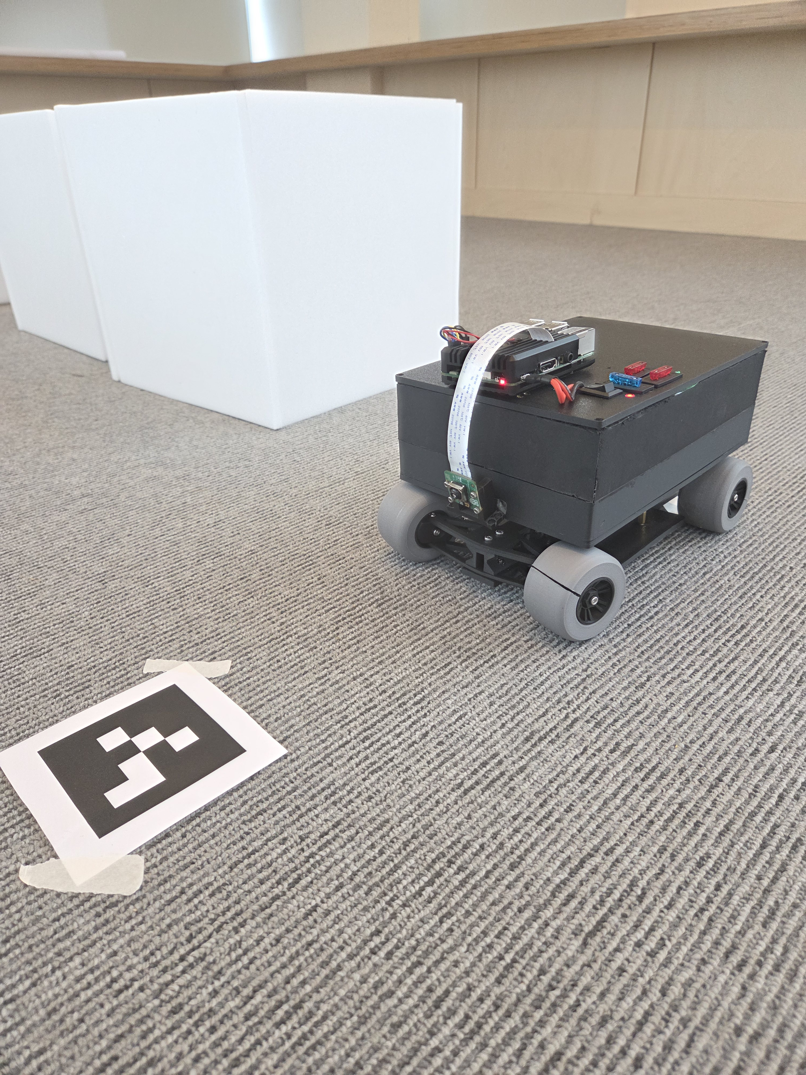
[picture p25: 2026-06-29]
media/images/test_1.jpg

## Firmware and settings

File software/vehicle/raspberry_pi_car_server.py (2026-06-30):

#!/usr/bin/env python3
# -*- coding: utf-8 -*-
"""
Raspberry Pi vehicle server: manual keyboard control + live ArUco camera.

웹 구조:
- templates/web.html: 기존 Web.html의 상단 디자인 유지 + 하단 카메라/방향키 패널 추가
- /video_feed: 실시간 카메라 MJPEG 스트림
- /api/route_markers: 웹에서 계산한 최적 경로의 ArUco ID 등록
- /api/drive_state: WASD 키 상태를 받아 ESC/서보 PWM 갱신
- /api/status: 상태 확인

자율주행 기능:
- 없음.
- /start, /stop 자율주행 루프를 사용하지 않음.
- 안전용 내부 endpoint로 /api/neutral과 /emergency_stop은 남겨 두지만, 웹 UI에는 중립 전송 버튼을 두지 않음.
"""

import json
import os
import time
import threading
from pathlib import Path
from typing import Dict, List, Optional, Set

import cv2
import numpy as np
from flask import Flask, Response, jsonify, render_template, request

# ============================================================
# HARDWARE / PWM SETTINGS
# 기존 코드의 하드웨어 값, ESC/서보 보정값을 여기에 그대로 옮겨 넣으세요.
# ============================================================

ESC_CHANNEL = 0          # 사용자가 확인한 ESC 채널
SERVO_CHANNEL = 1        # 기존 서보 채널이 다르면 기존 값으로 수정
PWM_FREQ = 50

# 예시 안전값. 기존 코드에 보정값이 있으면 반드시 기존 값을 유지하세요.
ESC_NEUTRAL_US = 1500
ESC_FORWARD_US = 1570
ESC_REVERSE_US = 1430

# 조향은 이전 방식처럼 서보 각도 기준으로 관리합니다.
# 단, 중심 PWM 1500us는 고정 유지합니다.
SERVO_MIN_ANGLE = 0
SERVO_MAX_ANGLE = 180
SERVO_MIN_US = 1000
SERVO_MAX_US = 2000
SERVO_CENTER_ANGLE = 22
SERVO_LEFT_ANGLE = 35
SERVO_RIGHT_ANGLE = 9
SERVO_CENTER_US = 1500

# 키 입력/heartbeat가 끊기면 자동 중립
COMMAND_TIMEOUT_SEC = 0.45

# Camera
# CAMERA_INDEX를 None으로 두면 /dev/video0~3과 0~3 index를 자동 탐색합니다.
# 특정 카메라만 강제로 쓰려면 0, 1, 2처럼 숫자로 지정하세요.
CAMERA_INDEX = None
CAMERA_CANDIDATES = [0, 1, 2, 3]
CAMERA_WIDTH = 640
CAMERA_HEIGHT = 480
CAMERA_FPS = 15
JPEG_QUALITY = 70

# auto: Picamera2 먼저 시도 후 OpenCV/V4L2 시도
# opencv: USB 카메라/OpenCV만 사용
# picamera2: CSI 카메라/Picamera2만 사용
CAMERA_BACKEND = os.environ.get("CAMERA_BACKEND", "auto").strip().lower()
BLACK_FRAME_MEAN_THRESHOLD = 8.0
BLACK_FRAME_STD_THRESHOLD = 4.0
BLACK_FRAME_RETRY_LIMIT = 15

# 환경변수로도 강제 지정 가능:
# CAMERA_INDEX=1 python3 raspberry_pi_car_server_manual_web.py
_env_camera_index = os.environ.get("CAMERA_INDEX")
if _env_camera_index is not None and _env_camera_index.strip() != "":
    try:
        CAMERA_INDEX = int(_env_camera_index)
    except ValueError:
        CAMERA_INDEX = None

# ArUco
# 기존 마커 생성 때 사용한 dictionary와 일치해야 합니다.
ARUCO_DICT_NAME = "DICT_4X4_50"

# 웹 격자 좌표와 실제 ArUco marker ID의 매핑 파일입니다.
# 기존처럼 이 파일 하나만 수정하면 전체 코드가 같은 매핑을 사용합니다.
GRID_MARKER_MAP_FILE = Path(__file__).with_name("grid_marker_map.json")

# ============================================================
# PCA9685
# ============================================================

HARDWARE_AVAILABLE = True
PCA9685_IMPORT_ERROR = None

try:
    import board
    import busio
    from adafruit_pca9685 import PCA9685
except Exception as exc:  # noqa: BLE001
    HARDWARE_AVAILABLE = False
    PCA9685_IMPORT_ERROR = repr(exc)


def us_to_duty_cycle(pulse_us: int, freq: int = PWM_FREQ) -> int:
    period_us = 1_000_000.0 / freq
    duty = int((pulse_us / period_us) * 0xFFFF)
    return max(0, min(0xFFFF, duty))


def servo_angle_to_us(angle: float) -> int:
    """Convert servo angle to PWM pulse width. Center angle is forced to 1500us."""
    if angle == SERVO_CENTER_ANGLE:
        return SERVO_CENTER_US

    angle = max(SERVO_MIN_ANGLE, min(SERVO_MAX_ANGLE, float(angle)))
    ratio = (angle - SERVO_MIN_ANGLE) / (SERVO_MAX_ANGLE - SERVO_MIN_ANGLE)
    pulse = SERVO_MIN_US + ratio * (SERVO_MAX_US - SERVO_MIN_US)
    return int(round(pulse))


SERVO_LEFT_US = servo_angle_to_us(SERVO_LEFT_ANGLE)
SERVO_RIGHT_US = servo_angle_to_us(SERVO_RIGHT_ANGLE)


class CarController:
    def __init__(self) -> None:
        self.lock = threading.Lock()
        self.last_command_ts = 0.0
        self.last_pwm = {
            "throttle_us": ESC_NEUTRAL_US,
            "servo_us": SERVO_CENTER_US,
        }
        self.last_state: Dict[str, bool] = {
            "up": False,
            "down": False,
            "left": False,
            "right": False,
        }
        self.pca = None

        if HARDWARE_AVAILABLE:
            i2c = busio.I2C(board.SCL, board.SDA)
            self.pca = PCA9685(i2c)
            self.pca.frequency = PWM_FREQ

        self.neutral()
        self.watchdog_thread = threading.Thread(target=self._watchdog_loop, daemon=True)
        self.watchdog_thread.start()

    def _write_us(self, channel: int, pulse_us: int) -> None:
        if self.pca is None:
            # PC 테스트 모드: 실제 PWM 출력 없음
            return
        self.pca.channels[channel].duty_cycle = us_to_duty_cycle(pulse_us)

    def neutral(self) -> Dict[str, int]:
        with self.lock:
            self._write_us(ESC_CHANNEL, ESC_NEUTRAL_US)
            self._write_us(SERVO_CHANNEL, SERVO_CENTER_US)
            self.last_state = {"up": False, "down": False, "left": False, "right": False}
            self.last_pwm = {
                "throttle_us": ESC_NEUTRAL_US,
                "servo_us": SERVO_CENTER_US,
                "servo_angle": SERVO_CENTER_ANGLE,
            }
            self.last_command_ts = time.time()
            return dict(self.last_pwm)

    def apply_keyboard_state(self, state: Dict[str, bool]) -> Dict[str, int]:
        up = bool(state.get("up", False))       # W
        down = bool(state.get("down", False))   # S
        left = bool(state.get("left", False))   # A
        right = bool(state.get("right", False)) # D

        # ESC: W/S가 없으면 1500us 중립.
        if up and not down:
            throttle_us = ESC_FORWARD_US
        elif down and not up:
            throttle_us = ESC_REVERSE_US
        else:
            throttle_us = ESC_NEUTRAL_US

        # SERVO: A 또는 D로 조작한 경우에만 좌/우 각도 출력.
        # A/D 입력이 없거나 둘 다 눌리면 무조건 1500us 중심각으로 복귀.
        if left and not right:
            servo_us = SERVO_LEFT_US
            servo_angle = SERVO_LEFT_ANGLE
        elif right and not left:
            servo_us = SERVO_RIGHT_US
            servo_angle = SERVO_RIGHT_ANGLE
        else:
            servo_us = SERVO_CENTER_US
            servo_angle = SERVO_CENTER_ANGLE

        with self.lock:
            self._write_us(ESC_CHANNEL, throttle_us)
            self._write_us(SERVO_CHANNEL, servo_us)
            self.last_state = {"up": up, "down": down, "left": left, "right": right}
            self.last_pwm = {
                "throttle_us": throttle_us,
                "servo_us": servo_us,
                "servo_angle": servo_angle,
            }
            self.last_command_ts = time.time()
            return dict(self.last_pwm)

    def _watchdog_loop(self) -> None:
        while True:
            time.sleep(0.05)
            with self.lock:
                elapsed = time.time() - self.last_command_ts
                state_active = any(self.last_state.values())
            if state_active and elapsed > COMMAND_TIMEOUT_SEC:
                self.neutral()

    def status(self) -> Dict[str, object]:
        with self.lock:
            return {
                "hardware_available": HARDWARE_AVAILABLE,
                "pca9685_import_error": PCA9685_IMPORT_ERROR,
                "last_state": dict(self.last_state),
                "last_pwm": dict(self.last_pwm),
                "last_command_age_sec": round(time.time() - self.last_command_ts, 3),
                "channels": {
                    "esc": ESC_CHANNEL,
                    "servo": SERVO_CHANNEL,
                },
                "pwm_us": {
                    "esc_neutral": ESC_NEUTRAL_US,
                    "esc_forward": ESC_FORWARD_US,
                    "esc_reverse": ESC_REVERSE_US,
                    "servo_center": SERVO_CENTER_US,
                    "servo_left": SERVO_LEFT_US,
                    "servo_right": SERVO_RIGHT_US,
                },
                "servo_angle": {
                    "center": SERVO_CENTER_ANGLE,
                    "left": SERVO_LEFT_ANGLE,
                    "right": SERVO_RIGHT_ANGLE,
                },
            }


# ============================================================
# ArUco / camera
# ============================================================

route_lock = threading.Lock()
optimal_route_marker_ids: Set[int] = set()
latest_route_cells: List[Dict[str, int]] = []


def get_aruco_dictionary():
    if not hasattr(cv2, "aruco"):
        return None

    if not hasattr(cv2.aruco, ARUCO_DICT_NAME):
        raise ValueError(f"Unknown ArUco dictionary: {ARUCO_DICT_NAME}")

    return cv2.aruco.getPredefinedDictionary(getattr(cv2.aruco, ARUCO_DICT_NAME))


def make_aruco_detector():
    aruco_dict = get_aruco_dictionary()
    if aruco_dict is None:
        return None, None, None

    if hasattr(cv2.aruco, "DetectorParameters"):
        params = cv2.aruco.DetectorParameters()
    else:
        params = cv2.aruco.DetectorParameters_create()

    if hasattr(cv2.aruco, "ArucoDetector"):
        detector = cv2.aruco.ArucoDetector(aruco_dict, params)
    else:
        detector = None

    return aruco_dict, params, detector


ARUCO_DICT, ARUCO_PARAMS, ARUCO_DETECTOR = make_aruco_detector()


def detect_markers(gray):
    if ARUCO_DICT is None:
        return [], None

    if ARUCO_DETECTOR is not None:
        corners, ids, _ = ARUCO_DETECTOR.detectMarkers(gray)
    else:
        corners, ids, _ = cv2.aruco.detectMarkers(gray, ARUCO_DICT, parameters=ARUCO_PARAMS)

    return corners, ids


def annotate_frame(frame):
    if ARUCO_DICT is None:
        cv2.putText(
            frame,
            "cv2.aruco not available. Install opencv-contrib-python.",
            (20, 40),
            cv2.FONT_HERSHEY_SIMPLEX,
            0.62,
            (0, 0, 255),
            2,
            cv2.LINE_AA,
        )
        return frame

    gray = cv2.cvtColor(frame, cv2.COLOR_BGR2GRAY)
    corners, ids = detect_markers(gray)

    with route_lock:
        route_ids = set(optimal_route_marker_ids)

    if ids is None or len(ids) == 0:
        cv2.putText(
            frame,
            "No ArUco marker detected",
            (20, 36),
            cv2.FONT_HERSHEY_SIMPLEX,
            0.72,
            (255, 255, 255),
            2,
            cv2.LINE_AA,
        )
        return frame

    for marker_corners, marker_id_arr in zip(corners, ids.flatten()):
        marker_id = int(marker_id_arr)
        pts = marker_corners.reshape((4, 2)).astype(int)

        is_route = marker_id in route_ids

        # OpenCV color is BGR.
        box_color = (0, 255, 255) if is_route else (255, 255, 255)
        text_color = (0, 255, 255) if is_route else (255, 255, 255)
        thickness = 4 if is_route else 2

        cv2.polylines(frame, [pts], True, box_color, thickness)

        center_x = int(pts[:, 0].mean())
        center_y = int(pts[:, 1].mean())
        cv2.circle(frame, (center_x, center_y), 6 if is_route else 4, box_color, -1)

        label = f"ROUTE ID {marker_id}" if is_route else f"ID {marker_id}"
        cv2.putText(
            frame,
            label,
            (pts[0][0], max(22, pts[0][1] - 10)),
            cv2.FONT_HERSHEY_SIMPLEX,
            0.68 if is_route else 0.56,
            text_color,
            2,
            cv2.LINE_AA,
        )

    cv2.putText(
        frame,
        f"Route marker IDs: {sorted(route_ids)}",
        (20, frame.shape[0] - 20),
        cv2.FONT_HERSHEY_SIMPLEX,
        0.55,
        (255, 255, 255),
        2,
        cv2.LINE_AA,
    )

    return frame


camera_status_lock = threading.Lock()
latest_camera_status: Dict[str, object] = {
    "opened": False,
    "backend": None,
    "selected_index": None,
    "tried": [],
    "last_error": None,
    "black_frame_count": 0,
}


def update_camera_status(**kwargs) -> None:
    with camera_status_lock:
        latest_camera_status.update(kwargs)


def get_camera_status_snapshot() -> Dict[str, object]:
    with camera_status_lock:
        return dict(latest_camera_status)


class CameraSource:
    def read(self):
        raise NotImplementedError

    def release(self) -> None:
        pass


class OpenCVCameraSource(CameraSource):
    def __init__(self, cap, index: int, backend_name: str) -> None:
        self.cap = cap
        self.index = index
        self.backend_name = backend_name

    def read(self):
        return self.cap.read()

    def release(self) -> None:
        try:
            self.cap.release()
        except Exception:
            pass


class Picamera2Source(CameraSource):
    def __init__(self, picam2) -> None:
        self.picam2 = picam2

    def read(self):
        try:
            frame = self.picam2.capture_array()
            if frame is None:
                return False, None

            # Picamera2 RGB888 -> OpenCV BGR
            if len(frame.shape) == 3 and frame.shape[2] == 3:
                frame = cv2.cvtColor(frame, cv2.COLOR_RGB2BGR)
            elif len(frame.shape) == 3 and frame.shape[2] == 4:
                frame = cv2.cvtColor(frame, cv2.COLOR_RGBA2BGR)

            return True, frame
        except Exception:
            return False, None

    def release(self) -> None:
        try:
            self.picam2.stop()
        except Exception:
            pass


def is_black_frame(frame) -> bool:
    if frame is None:
        return True
    try:
        gray = cv2.cvtColor(frame, cv2.COLOR_BGR2GRAY)
        return float(gray.mean()) < BLACK_FRAME_MEAN_THRESHOLD and float(gray.std()) < BLACK_FRAME_STD_THRESHOLD
    except Exception:
        return False


def open_picamera2_source() -> Optional[CameraSource]:
    tried = [{"backend": "Picamera2", "opened": False}]

    try:
        from picamera2 import Picamera2  # type: ignore

        picam2 = Picamera2()
        config = picam2.create_preview_configuration(
            main={"format": "RGB888", "size": (CAMERA_WIDTH, CAMERA_HEIGHT)},
            controls={"FrameRate": CAMERA_FPS},
        )
        picam2.configure(config)
        picam2.start()
        time.sleep(0.6)

        source = Picamera2Source(picam2)
        ok, frame = source.read()
        if ok and frame is not None and not is_black_frame(frame):
            tried[-1]["opened"] = True
            update_camera_status(
                opened=True,
                backend="Picamera2",
                selected_index="picamera2",
                tried=tried,
                last_error=None,
                black_frame_count=0,
            )
            return source

        # Some cameras need more exposure warm-up time.
        black_count = 0
        for _ in range(10):
            time.sleep(0.12)
            ok, frame = source.read()
            if ok and frame is not None and not is_black_frame(frame):
                tried[-1]["opened"] = True
                update_camera_status(
                    opened=True,
                    backend="Picamera2",
                    selected_index="picamera2",
                    tried=tried,
                    last_error=None,
                    black_frame_count=black_count,
                )
                return source
            black_count += 1

        source.release()
        tried[-1]["black_frame_failed"] = True
        update_camera_status(
            opened=False,
            backend="Picamera2",
            selected_index=None,
            tried=tried,
            last_error="Picamera2 opened but returned black frames.",
            black_frame_count=black_count,
        )
        return None

    except Exception as exc:  # noqa: BLE001
        tried[-1]["error"] = repr(exc)
        update_camera_status(
            opened=False,
            backend="Picamera2",
            selected_index=None,
            tried=tried,
            last_error=repr(exc),
        )
        return None


def open_camera_by_index(index: int):
    """
    Open camera through V4L2 first. This is the normal path for USB webcams
    and for cameras exposed as /dev/video*.
    """
    backends = []
    if hasattr(cv2, "CAP_V4L2"):
        backends.append(("CAP_V4L2", cv2.CAP_V4L2))
    backends.append(("DEFAULT", 0))

    tried = []

    for backend_name, backend_id in backends:
        try:
            if backend_name == "DEFAULT":
                cap = cv2.VideoCapture(index)
            else:
                cap = cv2.VideoCapture(index, backend_id)

            if hasattr(cv2, "VideoWriter_fourcc"):
                cap.set(cv2.CAP_PROP_FOURCC, cv2.VideoWriter_fourcc(*"MJPG"))
            cap.set(cv2.CAP_PROP_FRAME_WIDTH, CAMERA_WIDTH)
            cap.set(cv2.CAP_PROP_FRAME_HEIGHT, CAMERA_HEIGHT)
            cap.set(cv2.CAP_PROP_FPS, CAMERA_FPS)
            if hasattr(cv2, "CAP_PROP_BUFFERSIZE"):
                cap.set(cv2.CAP_PROP_BUFFERSIZE, 1)

            opened = bool(cap.isOpened())
            tried.append({"index": index, "backend": backend_name, "opened": opened})

            if opened:
                # Warm-up frames. Some cameras output black frames immediately after open.
                ok = False
                frame = None
                black_count = 0

                for _ in range(12):
                    ok, frame = cap.read()
                    if ok and frame is not None and not is_black_frame(frame):
                        update_camera_status(
                            opened=True,
                            backend=backend_name,
                            selected_index=index,
                            tried=tried,
                            last_error=None,
                            black_frame_count=black_count,
                        )
                        return OpenCVCameraSource(cap, index, backend_name), tried

                    if ok and frame is not None and is_black_frame(frame):
                        black_count += 1

                    time.sleep(0.08)

                cap.release()
                tried[-1]["opened"] = False
                tried[-1]["black_frame_failed"] = True
                tried[-1]["black_frame_count"] = black_count

        except Exception as exc:  # noqa: BLE001
            tried.append({
                "index": index,
                "backend": backend_name,
                "opened": False,
                "error": repr(exc),
            })

    return None, tried


def open_first_available_camera() -> Optional[CameraSource]:
    """
    Try Picamera2 first for CSI cameras, then OpenCV/V4L2 for USB or /dev/video* cameras.
    """
    all_tried = []

    if CAMERA_BACKEND in ("auto", "picamera2"):
        source = open_picamera2_source()
        picam_status = get_camera_status_snapshot()
        all_tried.extend(picam_status.get("tried", []))
        if source is not None:
            return source
        if CAMERA_BACKEND == "picamera2":
            return None

    if CAMERA_BACKEND in ("auto", "opencv", "v4l2"):
        candidate_indices = [CAMERA_INDEX] if CAMERA_INDEX is not None else list(CAMERA_CANDIDATES)

        for index in candidate_indices:
            source, tried = open_camera_by_index(int(index))
            all_tried.extend(tried)
            if source is not None:
                return source

    update_camera_status(
        opened=False,
        backend=None,
        selected_index=None,
        tried=all_tried,
        last_error=(
            "No usable camera frame. The device may be absent, busy, unsupported by OpenCV, "
            "or returning black frames. Try CAMERA_BACKEND=picamera2 for CSI camera or "
            "CAMERA_INDEX=1 for USB camera."
        ),
    )
    return None



def placeholder_frame(message: str):
    frame = np.full((480, 640, 3), 245, dtype=np.uint8)
    cv2.putText(
        frame,
        message,
        (32, 240),
        cv2.FONT_HERSHEY_SIMPLEX,
        0.8,
        (0, 0, 0),
        2,
        cv2.LINE_AA,
    )
    return frame
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

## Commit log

2026-04-08 Create mechanical, cad folders and README.md file
2026-06-29 Revise README for project overview and details
    Updated project name and expanded project overview, features, system flowchart, hardware components, power design, motor and steering control, software functions, limitations, and future improvements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
2026-06-29 Add comprehensive project documentation in Korean
    Added detailed project overview, features, system flow, hardware components, power design, motor and steering control, software functions, limitations, future improvements, and team roles.
2026-06-29 Create cad
2026-06-30 Create Korean README for vehicle project
    Added Korean README for Raspberry Pi car server setup and usage instructions.
2026-06-30 Fix formatting in BMS selection table in README.ko.md
